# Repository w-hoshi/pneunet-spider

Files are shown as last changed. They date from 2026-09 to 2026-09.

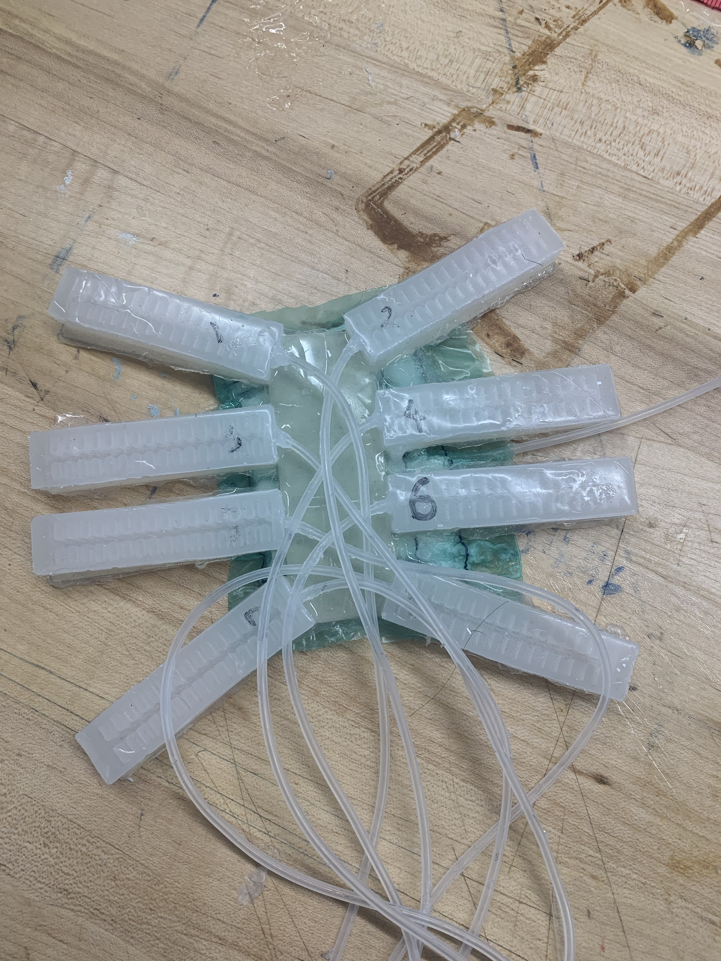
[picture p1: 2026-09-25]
images/Spider.jpg

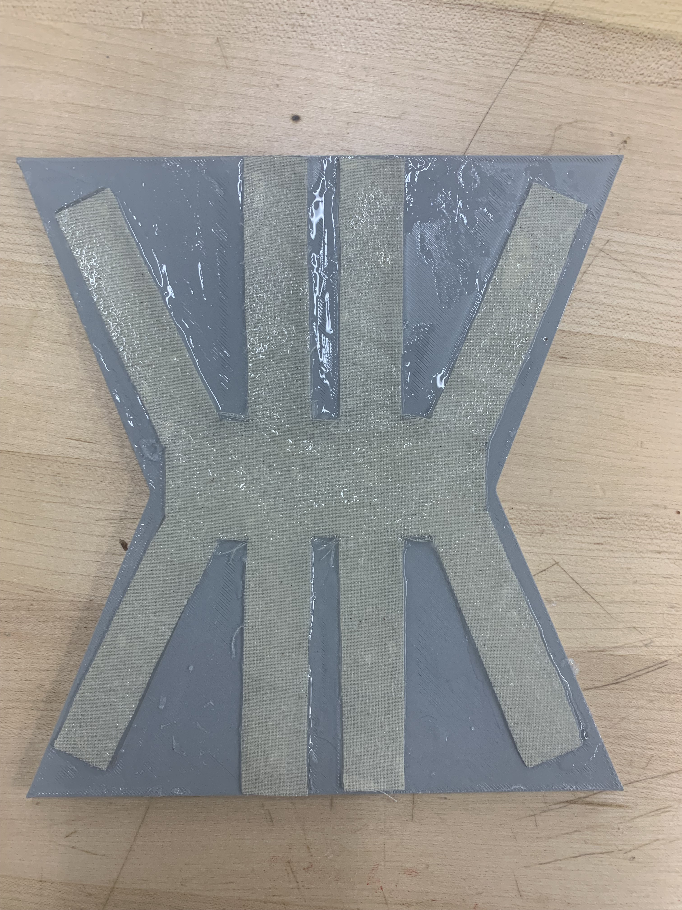
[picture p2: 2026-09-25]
images/Body_mold.jpg

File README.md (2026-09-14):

# Soft Robotic Spider

An eight legged soft robot with pneumatic bending legs and a variable stiffness body. The legs are PneuNet actuators cast from Ecoflex 00-30 with a fabric strain limiting layer. The body holds a laminar jamming pouch (TPE filled with sugar and paper sheets) that stiffens under vacuum, so the robot can stay compliant while crawling and lock up when it needs to hold a load.

Video of crawling and grasping: https://youtu.be/Sf3-M5LHtmc

## Results

- Crawl speed on a flat wood track: about 0.99 mm/s over five runs.
- Handles loose terrain (rice covered track) without trouble. Gets stuck in narrow passages where walls fold the legs under the body.
- Grasps by curling all eight legs around an object. Lifted up to 200 g.
- Modeling: fit a constant curvature model to the leg backbone at three pressures. The fit is tight at low pressure, still usable at medium, and RMS error roughly doubles at high pressure where the base bends more than the tip. A piecewise constant curvature model would be the next step.

## Repo contents

- `CAD/` STL files for the leg and body molds.

## Fabrication notes

Legs are cast in a 3D printed two part mold, then bonded to the strain limiting layer with a thin coat of uncured Ecoflex. Inspect the chambers for tears after demolding and again after bonding. The jamming pouch uses an "air mattress" column pattern so the sugar stays distributed along the length instead of pooling at one end.

## Credits

Course project. I designed the final leg geometry, made the molds in SolidWorks, and manufactured the legs. Several geometries were tested for inflation behavior before landing on this one. The variable stiffness components were developed by Erik Rodriguez-Canales.

## References

- Ilievski et al., Soft robotics for chemists, Angew. Chem. Int. Ed., 2011.
- Shepherd et al., Multigait soft robot, PNAS, 2011.
- Brown et al., Universal robotic gripper based on the jamming of granular material, PNAS, 2010.
- Amend et al., A positive pressure universal gripper based on the jamming of granular material, IEEE T-RO, 2012.

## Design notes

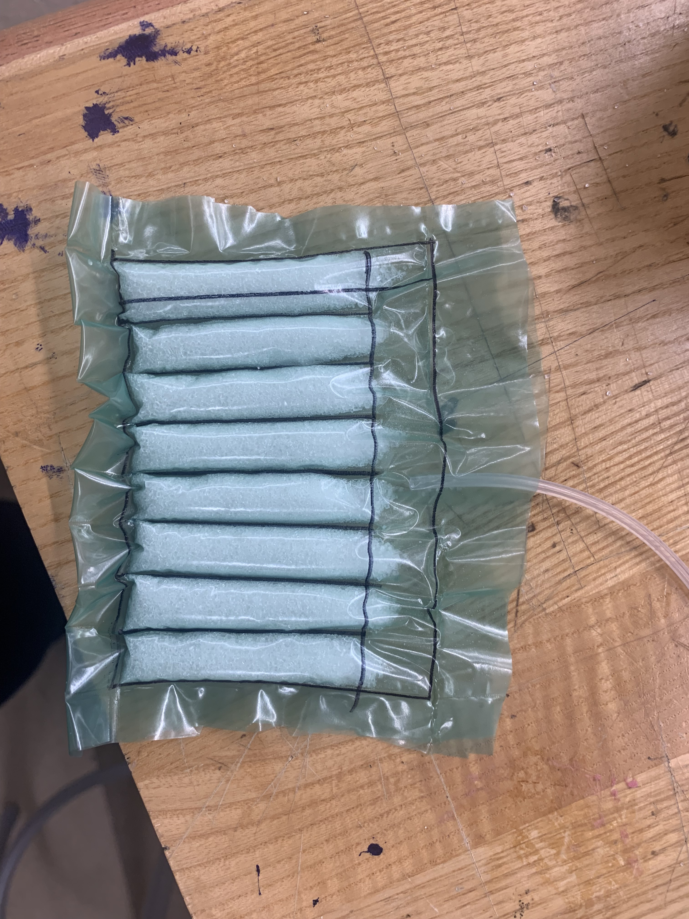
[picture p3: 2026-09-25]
images/Completed_Jammer.jpg

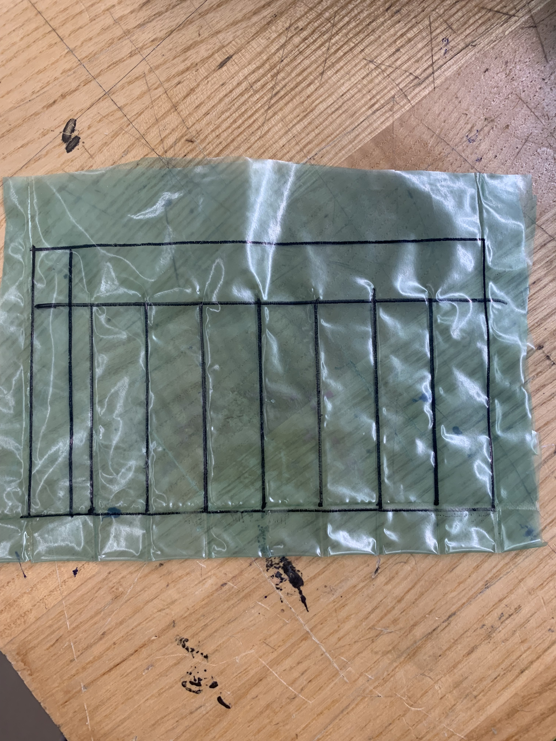
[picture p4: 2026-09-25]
images/Jammer_plastic.jpg

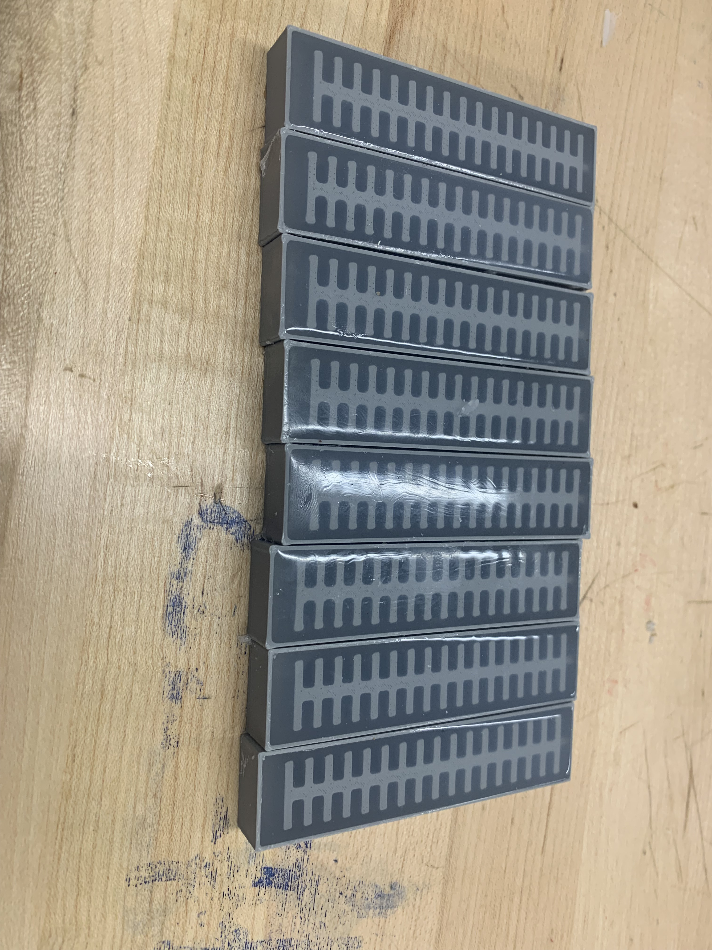
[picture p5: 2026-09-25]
images/Leg_molds.jpg

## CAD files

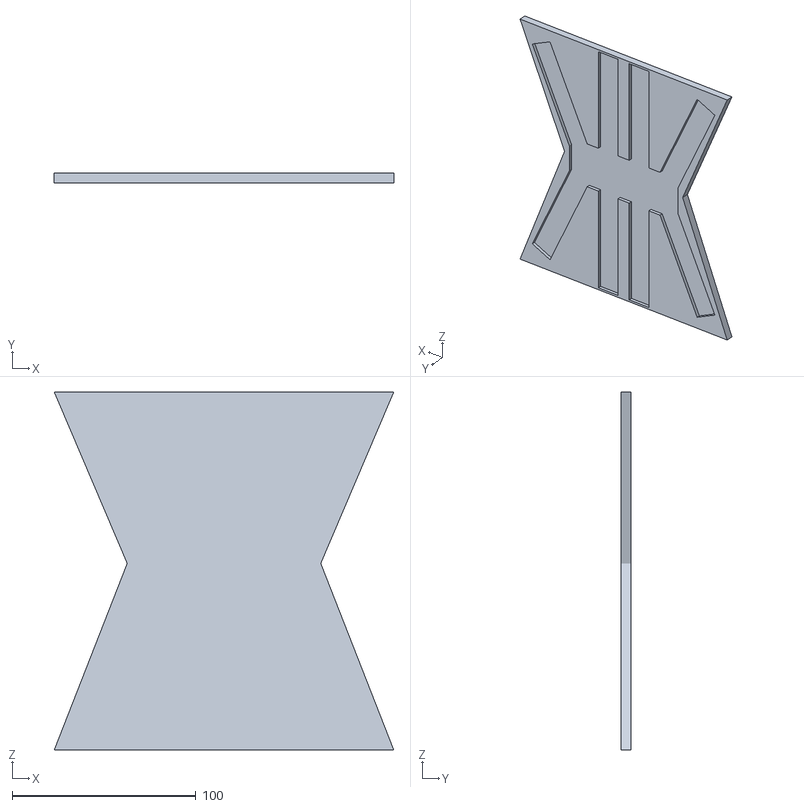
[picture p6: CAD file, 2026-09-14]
CAD/SpiderBodyMold.STL
184.9 x 5.50 x 195.0

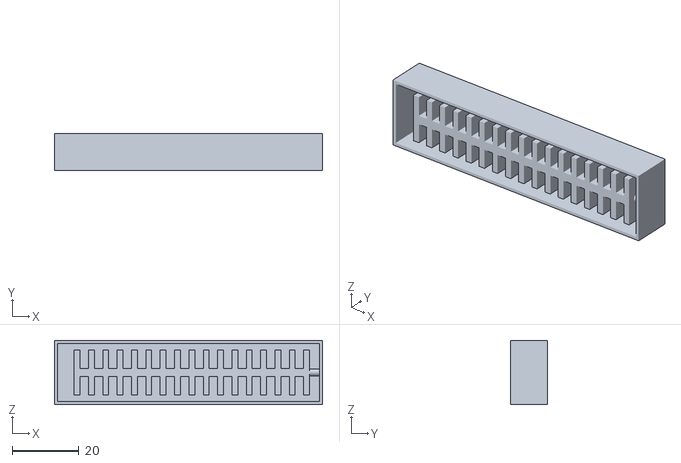
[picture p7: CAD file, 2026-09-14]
CAD/ArmTopMold.STL
80.3 x 11.0 x 19.3
